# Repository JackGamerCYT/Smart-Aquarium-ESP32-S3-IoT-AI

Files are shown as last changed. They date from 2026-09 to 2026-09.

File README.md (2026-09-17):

# 🐠 SMART AQUARIUM IoT – BỂ CÁ THÔNG MINH (ESP32-S3)

Hệ thống quản lý bể cá mini 4.5 L: **tự động làm mát** bằng sò Peltier (hysteresis 25.5–27.0°C), **cho cá ăn theo lịch thời gian thực** (RTC DS3231 – chạy cả khi mất Internet/mất điện), hiển thị OLED tại chỗ và **giám sát/điều khiển từ xa** qua MQTT + Web Dashboard trên Vercel.

> Môn **Embedded System Design** – GVHD: Huỳnh Hoàng Hà – Trường ĐH Sư phạm Kỹ thuật TP.HCM (HCMUTE)
> Trạng thái: **Tuần 6 – System Integration** · Firmware **v2.2.0** · Dashboard **v4** · **Vercel API + Postgres (Neon) + HiveMQ** · Phần cứng **Rev2**

## 📁 Cấu trúc repository

```text
smart-aquarium-ai/
├── README.md                         # README tổng (file này)
├── index.html                        # Web Dashboard v4 (HiveMQ realtime + Vercel API + Chart.js)
├── api/                              # Vercel Functions: ingest, history, stats, feeds, events, export, config, health, cron
├── lib/                              # Kết nối Postgres (pg), tiện ích HTTP, schema
├── db/schema.sql                     # Cấu trúc bảng (API tự tạo, không cần chạy tay)
├── package.json                      # Dependency: pg
├── vercel.json                       # Cron dọn dữ liệu + header
├── .env.example                      # Danh sách Environment Variables
├── docs/
│   ├── README.md
│   ├── 01_TONG_KET_KET_QUA_TUAN.md    # Tổng kết kết quả từng tuần (W1 → W6)
│   ├── 02_DAC_TA_HE_THONG.md          # Đặc tả: yêu cầu, FR/NFR, kiến trúc, MQTT, state machine
│   ├── 03_LO_TRINH_TIEN_DO_PHAN_CONG.md # Lộ trình 9 tuần, tiến độ, phân công, quản lý cá nhân
│   ├── 04_PHAN_CUNG_REV2_RTC.md       # Làm lại toàn bộ mạch + tích hợp RTC DS3231
│   └── 05_WEB_DATABASE.md             # Triển khai Vercel + Postgres + HiveMQ (public/Cloud)
├── firmware/
│   ├── README.md
│   └── smart_aquarium_esp32s3/
│       └── smart_aquarium_esp32s3.ino # Firmware v2.2.0
├── hardware/
│   ├── README.md
│   └── danh_sach_mua_sam_v1.1.xlsx     # BOM & dự toán (cập nhật Rev2)
├── report/
│   ├── README.md
│   └── Report_Chuong1_2.docx           # Báo cáo: Chương 1 Tổng quan, Chương 2 Cơ sở lý thuyết
└── weekly/
    └── W06/README.md                  # Bản nộp tuần 6
```

## ⚙️ Tính năng chính (v2.2.0)

| Nhóm | Tính năng |
|---|---|
| Nhiệt độ | DS18B20 đọc bất đồng bộ 1 s · hysteresis AUTO · MANUAL tự hết hạn 30 phút · nghỉ tối thiểu 60 s · quạt chạy trễ 60 s |
| Cho ăn | Servo MG90S · nút FEED / Web / **lịch tối đa 4 mốc theo RTC** · tạm dừng bơm · chống cho ăn lặp & quá tay |
| Thời gian | **DS3231** giữ giờ bằng pin · NTP → RTC · đặt giờ từ trình duyệt · ngắt SQW 1 Hz |
| An toàn | Lỗi cảm biến → tắt sò · ≥30°C ép bật · ≤22°C ép tắt · bơm tắt → khóa sò · còi cảnh báo |
| IoT | MQTT HiveMQ public (1883) hoặc **HiveMQ Cloud (TLS 8883 + user/pass)** · telemetry 2 s · event · LWT online/offline · **ACK cho mỗi lệnh web** · lưu cấu hình NVS |
| Database | **Vercel Functions + Postgres (Neon)**: ESP32 gửi theo lô lên `/api/ingest` (task FreeRTOS riêng) · web vẽ lịch sử 1h–7 ngày, KPI, cho ăn theo ngày, nhật ký, xuất CSV · cron dọn dữ liệu cũ |

## 📌 Sơ đồ chân Rev2 (tóm tắt)

| Linh kiện | GPIO | Ghi chú |
|---|---|---|
| DS18B20 | 4 | Trở kéo 4.7k lên **3V3** |
| OLED SH1106 + DS3231 (I2C) | SDA 8 / SCL 9 | Cấp **3V3**, 0x3C / 0x68 |
| DS3231 SQW | 7 | Ngắt 1 Hz |
| Relay CH1 – Sò Peltier | 19 | Active-LOW (giữ như mạch cũ) |
| Relay CH2 – Bơm | 18 | Active-LOW (giữ như mạch cũ) |
| Quạt (IRLZ44N) | 15 | Chạy trễ 60 s |
| Servo MG90S | 13 | Tụ 1000 µF |
| Còi | 12 | như mạch cũ |
| Nút BOOT / FEED | 0 / 16 | Giữ BOOT 2 s = Self-Test |

Chi tiết đấu nối, nguồn 12V-10A, quy trình bring-up: **[docs/04_PHAN_CUNG_REV2_RTC.md](docs/04_PHAN_CUNG_REV2_RTC.md)**

## 🚀 Bắt đầu nhanh

1. **Firmware:** xem [firmware/README.md](firmware/README.md) – cài thư viện, sửa Wi-Fi & `TOPIC_BASE`, nạp bằng Arduino IDE.
2. **Vercel + Database + HiveMQ:** push GitHub → Vercel **Storage → Neon** → nhập Environment Variables (xem `.env.example`) → Redeploy. Chi tiết: [docs/05_WEB_DATABASE.md](docs/05_WEB_DATABASE.md).
3. **Kiểm tra:** mở `https://<app>.vercel.app/api/health`.
4. **Phần cứng:** lắp theo thứ tự B1 → B10 trong `docs/04`.

## 👥 Nhóm

Xem bảng thành viên & phân công: [docs/03_LO_TRINH_TIEN_DO_PHAN_CONG.md](docs/03_LO_TRINH_TIEN_DO_PHAN_CONG.md)

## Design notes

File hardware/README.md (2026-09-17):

# Hardware

- `danh_sach_mua_sam_v1.1.xlsx` – BOM & dự toán. Cột **"Thay đổi v1.1"** ghi rõ mục thay/bổ sung so với v1.0 (OLED thay TFT, nguồn 10A, relay, bơm, cầu chì, driver, connector). Giá mục mới là ước tính.
- Sơ đồ đấu nối, ngân sách công suất, bố trí PCB, quy trình bring-up: `../docs/04_PHAN_CUNG_REV2_RTC.md`
- Ảnh mạch thực tế / sơ đồ vẽ tay: đặt vào thư mục `hardware/images/` khi hàn xong.

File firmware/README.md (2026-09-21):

# Firmware – ESP32-S3 (v3.2.0)

## Cài đặt
1. Arduino IDE → *Preferences* → Board URL: `https://espressif.github.io/arduino-esp32/package_esp32_index.json`
2. *Boards Manager* → cài **esp32 by Espressif** (2.0.x hoặc 3.x) → chọn **ESP32S3 Dev Module**
   (PSRAM: *OPI PSRAM* cho N8R8/N16R8 · Flash size theo board)
3. *Library Manager* cài: `PubSubClient`, `ArduinoJson` (v7), `OneWire`, `DallasTemperature`, `ESP32Servo`, `RTClib` (Adafruit).
   **Màn LCD không cần thư viện** – driver đã viết sẵn trong firmware. (Không cần U8g2 / LiquidCrystal_I2C / Adafruit GFX.)
4. Wi-Fi `HO TRO SINH VIEN`, topic `smartaquarium_node2026` đã điền sẵn. Giữ `DB_ENABLED = false` (backend Render ghi database).
5. Cắm USB vào cổng **UART/COM** → Upload → Serial Monitor **115200**.

## Thư mục
| Sketch | Dùng khi |
|---|---|
| `smart_aquarium_esp32s3/` | Firmware chính |
| `test_lcd/` | Kiểm tra riêng màn LCD (tô kín ô, hiện chữ 4 dòng) |
| `test_tim_chan_i2c/` | Tự dò LCD/RTC đang thật sự cắm ở chân nào, đo điện dây SDA/SCL |
| `test_ds18b20/` | Web báo **Mất cảm biến / ERR**: kiểm tra trở kéo, dò chân, đọc 20 lần đếm lỗi |

## Sơ đồ chân (giữ nguyên mạch cũ)
| Chức năng | GPIO | Ghi chú |
|---|---|---|
| LCD + DS3231 – SDA / SCL | **8 / 9** | LCD cấp **5V** (qua module chuyển mức BSS138 nếu có), DS3231 cấp 3V3 |
| DS18B20 | 4 | ĐỎ→3V3 · ĐEN→GND · VÀNG→GPIO4 · **trở 4.7k giữa VÀNG và ĐỎ** (kéo nội chỉ dùng tạm) |
| DS3231 SQW | 7 | Tùy chọn |
| Relay sò / bơm | 19 / 18 | Active-LOW |
| Quạt MOSFET / Servo / Còi | 15 / 13 / 12 | |
| Nút BOOT / Cho ăn | 0 / 16 | Giữ BOOT 2 s = Self-Test |

## Màn LCD I2C
- **LCD 1602 (16x2):** tự lật trang mỗi 3 s — giờ & nhiệt độ → sò/bơm & lịch cho ăn → (cảnh báo nếu có).
- **LCD 2004 (20x4):** hiện đủ trên 1 trang.
- Đổi loại màn **không cần nạp lại**: gõ `lcd 1602` hoặc `lcd 2004` ở Serial, hoặc bấm nút trên web (lưu NVS).

| Hiện tượng | Nguyên nhân | Cách sửa |
|---|---|---|
| Đèn nền sáng, không có chữ / chỉ thấy ô đen | Tương phản | **Vặn biến trở xanh** sau lưng mạch I2C |
| Đèn nền không sáng | Thiếu 5V/GND, hoặc mất jumper LED | Kiểm tra VCC=5V, cắm jumper "LED" sau mạch I2C |
| Serial `[I2C] ... KHONG CO` | Dây / nguồn | SDA→GPIO8, SCL→GPIO9 (hay bị đảo), GND chung |
| Serial `[LCD] KHONG thay LCD` nhưng có `68` | Dây riêng của LCD | Nạp `test_tim_chan_i2c.ino` |
| Chữ bị cắt / sai dòng | Chọn sai kích thước | `lcd 1602` / `lcd 2004` |

## Lệnh Serial Monitor (Newline)
`so on` · `so off` · `bom on` · `bom off` · `an` · `auto` · `test` · `status` · `lcd test` · `lcd 1602` · `lcd 2004` · `i2c`

## Cấu trúc code
| Mục | Hàm chính |
|---|---|
| Thời gian thực | `initTime()`, `handleTimeSync()`, `seedSystemFromRtc()`, `writeRtcFromSystem()` |
| Nhiệt độ | `updateSensor()`, `controlTemperature()`, `setChiller()` |
| Cho ăn | `startFeeding()`, `updateFeeding()` (FSM), `checkSchedule()` |
| LCD (driver tự viết) | `lcdInit()`, `lcdRow()` (chỉ ghi dòng thay đổi), `renderLCD()`, `lcdTestPattern()`, `handleLcdHotplug()` |
| Chẩn đoán I2C | `i2cLineHasPullup()`, `i2cScan()`, `printI2cReport()` |
| IoT | `handleConnectivity()`, `sendTelemetry()`, `mqttCallback()` + `sendAck()`, `publishEvent()` |
| Độ tin cậy | `bufferPush()` / `bufferFlush()` (đệm 240 bản ghi + gửi bù), SAFE MODE sau 30 s mất broker |
| Bảo trì | `runSelfTest()`, `handleSerialCommand()` |

## Kiểm tra đã thực hiện
- Kiểm tra cú pháp C++ (g++ -Wall -Wextra, header giả lập Arduino + ArduinoJson thật): **0 lỗi**.
- Driver LCD chạy trên bộ **mô phỏng HD44780 + PCF8574**: khởi tạo 4-bit đúng, hiển thị đúng cả 16x2 và 20x4.
- ⚠️ **Chưa biên dịch bằng toolchain ESP32 và chưa chạy trên phần cứng thật** → bấm Verify trong Arduino IDE trước khi nạp.

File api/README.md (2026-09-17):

# API (Vercel Functions)

| Endpoint | Method | Dùng bởi | Mô tả |
|---|---|---|---|
| `/api/ingest` | POST | ESP32 | Header `x-device-key`. Body `{"items":[{"t":"telemetry"\|"events","r":{...}}]}` (≤ 60) |
| `/api/history?hours=24` | GET | Web | Nhiệt độ avg/min/max + % sò chạy theo bucket |
| `/api/stats?hours=24` | GET | Web | KPI |
| `/api/feeds?days=7` | GET | Web | Số lần cho ăn/ngày |
| `/api/events?type=&limit=100` | GET | Web | Nhật ký |
| `/api/export?hours=24` | GET | Web | CSV |
| `/api/config` | GET | Web | MQTT URL, topic, tài khoản web (từ env) |
| `/api/health` | GET | Người dùng | Kiểm tra env + DB |
| `/api/cron/cleanup` | GET | Vercel Cron | Xóa dữ liệu cũ (`Authorization: Bearer CRON_SECRET`) |

Biến môi trường: xem `../.env.example`. Hướng dẫn: `../docs/05_WEB_DATABASE.md`.

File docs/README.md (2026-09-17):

# Docs

| File | Nội dung |
|---|---|
| `01_TONG_KET_KET_QUA_TUAN.md` | Kết quả W1–W6, minh chứng, vướng mắc |
| `02_DAC_TA_HE_THONG.md` | Requirement analysis, FR/NFR, kiến trúc, interface, MQTT, state machine, traceability |
| `03_LO_TRINH_TIEN_DO_PHAN_CONG.md` | Roadmap 9 tuần, bảng task W6, kế hoạch W7–W9, rủi ro, quản lý công việc cá nhân |
| `04_PHAN_CUNG_REV2_RTC.md` | Lỗi mạch Rev1 & cách làm lại, pinout Rev2, đấu nối RTC DS3231, bring-up, test case RTC |
| `05_WEB_DATABASE.md` | Kiến trúc Web ↔ Vercel API/Postgres ↔ ESP32 ↔ HiveMQ, luồng ACK, API, triển khai từng bước, lỗi thường gặp |

Sơ đồ `mermaid` hiển thị trực tiếp trên GitHub.

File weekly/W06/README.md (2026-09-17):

# Tuần 6 – System Integration (14/09 – 20/09/2026)

**Output yêu cầu:** Integrated System / Prototype

## Nộp tuần này
| Hạng mục | File |
|---|---|
| Tổng kết kết quả từng tuần | `docs/01_TONG_KET_KET_QUA_TUAN.md` |
| Đặc tả hệ thống | `docs/02_DAC_TA_HE_THONG.md` |
| Lộ trình / tiến độ / phân công | `docs/03_LO_TRINH_TIEN_DO_PHAN_CONG.md` |
| Làm lại mạch + RTC (Rel) | `docs/04_PHAN_CUNG_REV2_RTC.md` |
| Firmware v2.0.0 | `firmware/smart_aquarium_esp32s3/` |
| Web v2 | `index.html` |
| BOM v1.1 | `hardware/danh_sach_mua_sam_v1.1.xlsx` |
| Report Chương 1, 2 | `report/Report_Chuong1_2.docx` |

## Minh chứng (bổ sung khi có)
- [ ] Ảnh mạch Rev2 đã hàn
- [ ] Ảnh I2C scanner thấy 0x3C / 0x57 / 0x68
- [ ] Video 3 use case tích hợp
- [ ] Link Vercel: …

## Lệnh push
```bash
git add .
git commit -m "W6: System integration - HW Rev2 + RTC DS3231, FW v2.0.0, docs, report ch1-2"
git push
```

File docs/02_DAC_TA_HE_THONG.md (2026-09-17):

# 02 – ĐẶC TẢ HỆ THỐNG: BỂ CÁ THÔNG MINH IoT (SMART AQUARIUM)

| Mục | Nội dung |
|---|---|
| Môn học | Embedded System Design – GVHD: Huỳnh Hoàng Hà – HCMUTE |
| Phiên bản tài liệu | v2.0 (cập nhật Tuần 6 – System Integration) |
| Phần cứng | ESP32-S3 DevKitC-1 · DS18B20 · DS3231 RTC · OLED 1.3" SH1106 · Relay 2 kênh · TEC1-12706 · MG90S |
| Phần mềm | Firmware Arduino C++ (FW 2.0.0) · Web Dashboard (HTML/Tailwind/MQTT.js/Chart.js) trên Vercel |
| Truyền thông | MQTT qua HiveMQ public broker (TCP 1883 cho thiết bị, WSS 8884 cho web) |

---

## 1. Bài toán & mục tiêu

Bể cá mini ~4.5 L (20×14×16 cm) có thể tích nước nhỏ nên **nhiệt độ thay đổi rất nhanh** theo nhiệt độ phòng (mùa nóng tại TP.HCM phòng có thể 32–35°C), trong khi đa số cá cảnh nhiệt đới sống tốt ở **24–28°C**. Người nuôi còn thường xuyên **quên cho cá ăn** hoặc cho ăn quá nhiều khi vắng nhà.

Hệ thống cần:
1. Giữ nhiệt độ nước trong dải an toàn một cách tự động.
2. Cho cá ăn tự động theo **giờ cố định**, kể cả khi mất Internet hoặc sau khi mất điện.
3. Cho phép theo dõi và điều khiển tại chỗ (màn hình, nút) và từ xa (web).
4. Cảnh báo khi có sự cố (quá nóng, quá lạnh, hỏng cảm biến, mất giờ).

## 2. Phạm vi

| Trong phạm vi | Ngoài phạm vi (hướng phát triển) |
|---|---|
| Làm **mát** bằng sò Peltier + water block | Sưởi nước (cần thêm heater) |
| Đo nhiệt độ nước 1 điểm | Đo pH, TDS, oxy hòa tan, mực nước |
| Cho ăn thức ăn dạng hạt khô bằng hộc xoay | Định lượng thức ăn theo gram |
| Điều khiển qua MQTT broker công cộng | Xác thực người dùng, TLS phía thiết bị, broker riêng |
| Lưu cấu hình/bộ đếm trên NVS của ESP32 | Cơ sở dữ liệu lịch sử dài hạn + phân tích AI (tùy chọn giai đoạn sau) |

---

## 3. Phân tích yêu cầu (Requirement Analysis – W1)

| Vấn đề / Use case | Nhu cầu người dùng | Câu hỏi phân tích | Giải pháp đề xuất |
|---|---|---|---|
| Nước nóng lên theo phòng | Nhiệt độ luôn an toàn cho cá | Làm mát bằng gì? Khi nào bật/tắt? | Cảm biến nhiệt chống nước + sò Peltier + điều khiển trễ (hysteresis) |
| Quên cho cá ăn | Cá được ăn đúng giờ | Mất mạng / mất điện thì sao? | Servo hộc xoay + **RTC có pin** + lịch lưu trong bộ nhớ |
| Cho ăn quá nhiều | Tránh bẩn nước, cá bệnh | Giới hạn thế nào? | Khoảng cách tối thiểu giữa 2 lần + giới hạn số lần/ngày |
| Thức ăn bị bơm hút | Thức ăn không bị lọc mất | Khi nào tắt bơm? | Tạm dừng bơm trong lúc cho ăn |
| Muốn xem tình trạng tại bể | Biết nhanh nhiệt độ, trạng thái | Hiển thị gì? | Màn hình OLED |
| Vắng nhà | Xem & điều khiển từ xa | Qua kênh nào? | Wi-Fi + MQTT + Web dashboard |
| Thiết bị hỏng âm thầm | Được báo sự cố | Phát hiện thế nào? | Kiểm tra giá trị cảm biến, còi, cảnh báo web |
| Bảo trì, lắp ráp | Kiểm tra nhanh phần cứng | Làm sao test không cần code? | Chế độ Self-Test bằng nút / web |

---

## 4. Yêu cầu chức năng (Functional Requirements – W2)

| ID | Yêu cầu | Đặc tả (hệ thống PHẢI…) | Kiểm chứng | TC |
|---|---|---|---|---|
| FR01 | Đo nhiệt độ | Đo nhiệt độ nước chu kỳ **1 s**, độ phân giải 0.125°C, sai số ≤ ±0.5°C | So sánh nhiệt kế chuẩn tại 3 điểm (≈20, 26, 32°C) | TC01 |
| FR02 | Làm mát tự động | Ở chế độ AUTO: bật sò khi T ≥ **SP_ON (27.0°C)**, tắt khi T ≤ **SP_OFF (25.5°C)** | Ngâm cảm biến nước ấm/mát, quan sát relay | TC02 |
| FR03 | Bảo vệ relay | Không bật lại sò trong **60 s** kể từ lần tắt gần nhất | Dao động T quanh ngưỡng, đo khoảng thời gian | TC03 |
| FR04 | Quạt tản nhiệt | Quạt chạy khi sò chạy và **thêm 60 s** sau khi sò tắt | Quan sát quạt sau khi tắt sò | TC04 |
| FR05 | Chế độ vận hành | Hỗ trợ **AUTO / MANUAL**; MANUAL tự trở về AUTO sau **30 phút** | Bật tay từ web, chờ hết hạn | TC05 |
| FR06 | Cho ăn thủ công | Cho ăn khi nhấn nút FEED hoặc lệnh web; servo 0°→110°→0° | Nhấn nút, quan sát hộc | TC06 |
| FR07 | Cho ăn theo lịch | Cho ăn tại tối đa **4 mốc giờ/ngày** theo giờ RTC, **không cần Internet** | Đặt lịch, ngắt Wi-Fi | TC07 |
| FR08 | Giữ thời gian | Giữ giờ khi mất điện nhờ DS3231 + pin; đồng bộ NTP khi có mạng; cho phép đặt giờ từ web | Rút điện 10 phút, bật lại không mạng | TC08 |
| FR09 | Chống cho ăn sai | Không cho ăn lặp sau reset; bỏ mốc nếu vừa cho ăn < 30 phút; tối đa **6 lần/ngày**; cho ăn bù nếu trễ ≤ 30 phút | Reset / bấm liên tục | TC09 |
| FR10 | Tạm dừng bơm | Tắt bơm khi bắt đầu cho ăn, bật lại **5 s** sau khi hộc đóng | Quan sát relay bơm | TC10 |
| FR11 | Hiển thị tại chỗ | OLED hiển thị: giờ, Wi-Fi/MQTT/RTC, nhiệt độ, chế độ, sò, bơm, quạt, lần ăn kế tiếp, số lần ăn, cảnh báo; làm mới 0.5 s | Quan sát | TC11 |
| FR12 | Giám sát từ xa | Gửi telemetry JSON mỗi **2 s**; dashboard hiển thị & vẽ biểu đồ | Mở web, so với OLED | TC12 |
| FR13 | Điều khiển từ xa | Nhận lệnh: sò, bơm, chế độ, cho ăn, self-test, lịch, ngưỡng, giờ, tắt còi | Gửi từng lệnh | TC13 |
| FR14 | Cảnh báo & an toàn | Lỗi cảm biến → tắt sò + còi; T ≥ 30°C → ép bật sò + còi; T ≤ 22°C → ép tắt sò + còi; bơm tắt → khóa sò | Rút DS18B20, ngâm nước nóng/lạnh | TC14 |
| FR15 | Self-Test | Kiểm tra còi, 2 relay, quạt, servo, DS18B20, RTC; báo PASS/FAIL trên OLED + web | Giữ BOOT 2 s | TC15 |
| FR16 | Lưu cấu hình | Lịch, ngưỡng, bộ đếm lưu NVS, không mất khi mất điện | Đổi lịch, rút điện | TC16 |

## 5. Yêu cầu phi chức năng (NFR)

| ID | Loại | Đặc tả |
|---|---|---|
| NFR01 | Thời gian đáp ứng | Lệnh web → cơ cấu chấp hành ≤ **1 s** (mạng ổn định) |
| NFR02 | Non-blocking | Vòng `loop()` không chặn quá 50 ms khi vận hành bình thường (trừ Self-Test) |
| NFR03 | Độ chính xác giờ | Lệch ≤ ±2 ppm (≈ ±1 phút/năm) khi offline nhờ DS3231 TCXO |
| NFR04 | Tin cậy | Tự kết nối lại Wi-Fi (30 s) & MQTT (5 s); không reset khi servo chạy |
| NFR05 | An toàn điện | Mọi chân tín hiệu ESP32 ≤ 3.3 V; có cầu chì; tải 12V dùng tiếp điểm NO |
| NFR06 | Nguồn | Toàn hệ chạy từ 1 adapter 12V-10A |
| NFR07 | Bảo trì | Module cắm bằng connector, có Self-Test, tài liệu README cho từng thư mục |
| NFR08 | Bảo mật (mức môn học) | Topic MQTT riêng theo nhóm; LWT báo online/offline |

---

## 6. Kiến trúc hệ thống (W3)

### 6.1 Sơ đồ khối tổng thể

```mermaid
flowchart TB
  subgraph INPUT
    DS18["DS18B20 (1-Wire)"]
    RTC["DS3231 RTC (I2C + SQW)"]
    BTN["Nút FEED / BOOT"]
  end
  subgraph MCU["ESP32-S3"]
    APP["Application: điều khiển nhiệt, lịch cho ăn, an toàn"]
  end
  subgraph OUTPUT
    R1["Relay CH1 → Sò Peltier"]
    R2["Relay CH2 → Bơm lọc"]
    FAN["MOSFET → Quạt"]
    SERVO["Servo MG90S → Hộc thức ăn"]
    OLED["OLED 1.3 SH1106"]
    BUZ["Còi"]
  end
  subgraph CLOUD
    BROKER["HiveMQ MQTT Broker"]
    WEB["Web Dashboard (Vercel)"]
    NTP["NTP server"]
  end
  DS18 --> APP
  RTC --> APP
  BTN --> APP
  APP --> R1 & R2 & FAN & SERVO & OLED & BUZ
  APP <-->|"Wi-Fi MQTT"| BROKER
  BROKER <-->|"WebSocket"| WEB
  NTP -->|"SNTP"| APP
```

### 6.2 Kiến trúc phần mềm firmware (phân lớp)

```text
┌───────────────────────────────────────────────────────────────┐
│ APPLICATION : controlTemperature() · checkSchedule() ·        │
│               handleAlarm() · mqttCallback() · runSelfTest()  │
├───────────────────────────────────────────────────────────────┤
│ SERVICES    : Time service (RTC⇄System⇄NTP) · Feed FSM ·      │
│               Buzzer FSM · Telemetry/Event · NVS settings     │
├───────────────────────────────────────────────────────────────┤
│ DRIVERS/LIB : DallasTemperature · RTClib · Adafruit_SH110X ·  │
│               ESP32Servo · PubSubClient · ArduinoJson         │
├───────────────────────────────────────────────────────────────┤
│ HAL (Arduino-ESP32 / ESP-IDF): GPIO · I2C · LEDC PWM · Wi-Fi ·│
│               SNTP · NVS · Interrupt                          │
├───────────────────────────────────────────────────────────────┤
│ HARDWARE    : ESP32-S3 + ngoại vi                             │
└───────────────────────────────────────────────────────────────┘
```

### 6.3 Phân chia HW/SW

| Chức năng | Phần cứng | Phần mềm |
|---|---|---|
| Đo nhiệt | DS18B20 + trở kéo | Đọc bất đồng bộ, lọc giá trị lỗi (−127, 85, ngoài 0–50°C) |
| Làm mát | Relay CH1, sò, water block, quạt, MOSFET | Hysteresis, thời gian nghỉ tối thiểu, quạt chạy trễ |
| Cho ăn | Servo MG90S, hộc xoay, tụ đệm | FSM quét góc, lịch RTC, chống cho ăn lặp |
| Thời gian | DS3231 (TCXO) + CR2032 | Đồng bộ NTP ⇄ RTC, múi giờ UTC+7, nhịp 1 Hz qua ngắt |
| HMI | OLED, còi, 2 nút | Giao diện OLED, mẫu tiếng còi, debounce nút |
| Kết nối | Wi-Fi ESP32-S3 | MQTT, JSON, tự kết nối lại, LWT |

### 6.4 Danh sách giao tiếp (Interface list)

| Giao tiếp | Thiết bị | Thông số |
|---|---|---|
| 1-Wire | DS18B20 | GPIO4, 11-bit (375 ms/lần chuyển đổi) |
| I2C | OLED SH1106 (0x3C), DS3231 (0x68), AT24C32 (0x57) | GPIO8 SDA / GPIO9 SCL, 400 kHz, 3V3 |
| GPIO ngắt | DS3231 SQW | GPIO7, FALLING, 1 Hz |
| GPIO ra | Relay CH1/CH2 (Active-LOW), MOSFET quạt, còi | GPIO19, GPIO18, GPIO15 (tùy chọn), GPIO12 |
| PWM | Servo | GPIO13, 50 Hz, 500–2400 µs |
| GPIO vào | Nút BOOT / FEED | GPIO0 / GPIO16, INPUT_PULLUP |
| Wi-Fi/MQTT | HiveMQ | `broker.hivemq.com:1883` (thiết bị), `wss://…:8884/mqtt` (web) |

### 6.5 Giao thức MQTT

`TOPIC_BASE = smartaquarium_node2026`

| Topic | Hướng | QoS/Retain | Nội dung |
|---|---|---|---|
| `…/telemetry` | ESP32 → Web | 0 / không | JSON trạng thái mỗi 2 s |
| `…/command` | Web → ESP32 | 0 / không | JSON lệnh |
| `…/status` | ESP32 → Web | 1 / **retain** | `online` / `offline` (LWT) |
| `…/event` | ESP32 → Web | 0 / không | Sự kiện: feed, alarm, time_sync, self_test… |

**Telemetry mẫu**
```json
{"temp":26.1,"chiller":false,"pump":true,"fan":false,"mode":"AUTO",
 "feed_today":1,"feed_count":12,"feeding":false,"time":"2026-09-17 10:21:05",
 "time_src":"NTP","rtc_ok":true,"rtc_temp":28.5,"next_feed":"17:30",
 "schedule":"07:00,17:30","sp_on":27,"sp_off":25.5,"alarm":"NONE",
 "rssi":-61,"uptime":3605,"fw":"2.0.0"}
```

**Lệnh**

| `device` | Tham số | Tác dụng |
|---|---|---|
| `chiller` | `action: ON/OFF` | Bật/tắt sò, chuyển MANUAL 30 phút |
| `pump` | `action: ON/OFF` | Bật/tắt bơm (tắt bơm ⇒ khóa sò) |
| `mode` | `action: AUTO/MANUAL` | Đổi chế độ |
| `feed` | – | Cho ăn ngay |
| `test` | – | Self-Test |
| `schedule` | `slots: "07:00,17:30"` | Đặt lịch (chuỗi rỗng = tắt) |
| `setpoint` | `on: 27.0, off: 25.5` | Đổi ngưỡng (off ≤ on − 0.5) |
| `time` | `epoch: 1789627265` | Đặt giờ từ trình duyệt → RTC |
| `alarm` | `action: MUTE` | Tắt còi cảnh báo hiện tại |

---

## 7. Hành vi hệ thống (State machine)

### 7.1 Điều khiển nhiệt độ

```mermaid
stateDiagram-v2
  [*] --> OFF
  OFF --> ON: T ≥ SP_ON và đã nghỉ ≥ 60s và bơm bật
  ON --> OFF: T ≤ SP_OFF
  ON --> OFF: lỗi cảm biến / T ≤ 22°C / bơm tắt
  OFF --> ON: T ≥ 30°C (ép bật, báo động)
```

### 7.2 Cho ăn

```mermaid
stateDiagram-v2
  [*] --> IDLE
  IDLE --> OPEN: nút / web / đến mốc lịch (tắt bơm)
  OPEN --> HOLD: servo đạt 110°
  HOLD --> CLOSE: sau 1 s
  CLOSE --> RESUME: servo về 0°, detach
  RESUME --> IDLE: sau 5 s bật lại bơm, +1 bộ đếm, lưu NVS
```

### 7.3 Nguồn thời gian

```text
Khởi động ─► DS3231 còn giờ? ─ có ─► giờ hệ thống = RTC (src=RTC)
                    │ không
                    ▼
            chờ NTP / lệnh web ─► (TIME_INVALID: tạm dừng lịch)
NTP đồng bộ ─► giờ hệ thống = NTP ─► ghi vào RTC (lần đầu + mỗi 6 giờ)
Mất Wi-Fi   ─► mỗi 10 phút nạp lại giờ hệ thống từ RTC (TCXO chính xác hơn thạch anh ESP32)
```

---

## 8. Ma trận truy vết (Traceability)

| Requirement | Chức năng firmware | Test case |
|---|---|---|
| FR01 | `updateSensor()` | TC01 |
| FR02, FR03, FR04 | `controlTemperature()`, `setChiller()`, `applyOutputs()` | TC02–TC04 |
| FR05 | `controlTemperature()` (MANUAL_TIMEOUT_MS) | TC05 |
| FR06, FR10 | `startFeeding()`, `updateFeeding()` | TC06, TC10 |
| FR07, FR09 | `checkSchedule()` | TC07, TC09, TC-RTC-04..07 |
| FR08 | `initTime()`, `handleTimeSync()`, lệnh `time` | TC08, TC-RTC-01..03, 08..10 |
| FR11 | `renderOLED()` | TC11 |
| FR12, FR13 | `sendTelemetry()`, `mqttCallback()` | TC12, TC13 |
| FR14 | `controlTemperature()`, `handleAlarm()` | TC14 |
| FR15 | `runSelfTest()` | TC15 |
| FR16 | `loadSettings()`, `saveFeedCounters()` | TC16 |

## 9. Ràng buộc & giả định

- Bể 4.5 L, phòng ≤ 35°C; sò 60 W đủ hạ vài °C cho thể tích này khi mặt nóng được tản nhiệt tốt (cần đo thực tế ở W7).
- Thức ăn dạng hạt khô, không vón cục.
- Wi-Fi 2.4 GHz; broker HiveMQ công cộng chỉ phục vụ học tập.
- Chi tiết mạch điện, bảng nối chân và quy trình lắp: xem **`docs/04_PHAN_CUNG_REV2_RTC.md`**.

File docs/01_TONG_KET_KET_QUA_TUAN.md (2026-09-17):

# 01 – TỔNG KẾT KẾT QUẢ THEO TUẦN

> Dự án: **Bể cá thông minh IoT (Smart Aquarium)** – Môn Embedded System Design (HCMUTE)
> Cập nhật: **17/09/2026 – Tuần 6** · Quy ước: ✅ hoàn thành · 🔄 đang làm · ⏳ chưa làm · ⚠️ phải làm lại
> *Ngày của từng tuần là dự kiến theo lịch 9 tuần – nhóm chỉnh lại theo lịch lớp thực tế. Cột "Minh chứng" điền link commit/ảnh/video.*

## Tổng quan tiến độ

| Tuần | Giai đoạn (theo roadmap môn) | Output yêu cầu | Trạng thái |
|---|---|---|---|
| W1 | Introduction & Requirement Analysis | Requirement Analysis + Proposed Solutions | ✅ |
| W2 | System Specification | System Specification | ✅ (bổ sung v2.0 ở W6) |
| W3 | Architecture & HW/SW Design | Architecture + HW/SW Design + BOM | ✅ (⚠️ sửa pinout/nguồn ở W6) |
| W4 | Prototype & Feasibility Validation | Validated Modules + Test Results | ✅ phần lớn module |
| W5 | Implementation | Working Modules + Source Code | ✅ FW v1 + Web v1 |
| W6 | System Integration | Integrated System / Prototype | 🔄 Rev2 phần cứng + RTC + FW v2 |
| W7 | Testing & Optimization | Test Results + Improved System | ⏳ |
| W8 | Finalization & Presentation | Final Prototype + Report + Slide | ⏳ (Report Ch.1–2 đã xong ở W6) |
| W9 | Evaluation | Final Evaluation | ⏳ |

---

## Tuần 1 – Phân tích yêu cầu
**Câu hỏi trung tâm:** *Hệ thống giải quyết vấn đề gì?*

| Kết quả | Minh chứng |
|---|---|
| Xác định bài toán: bể mini 4.5 L nóng nhanh theo phòng; quên/cho ăn quá tay khi vắng nhà | `docs/02_DAC_TA_HE_THONG.md` §1 |
| Bảng Requirement Analysis (8 use case) + giải pháp đề xuất | `docs/02_DAC_TA_HE_THONG.md` §3 |
| Thành lập nhóm, tạo repo GitHub, nhóm Zalo | Link repo: `…` |

## Tuần 2 – Đặc tả hệ thống
**Câu hỏi trung tâm:** *Hệ thống chính xác phải làm gì?*

| Kết quả | Minh chứng |
|---|---|
| Đặc tả chức năng: làm mát hysteresis 25.5–27.0°C, cho ăn servo, OLED, IoT MQTT | `TONG_HOP_HE_THONG_HO_CA_SMART.md` |
| Chọn phương án làm mát bằng sò Peltier + water block (thay vì quạt thổi mặt nước) | Slide/biên bản nhóm |
| **Bổ sung W6:** 16 FR + 8 NFR có tiêu chí kiểm chứng, ma trận truy vết | `docs/02_DAC_TA_HE_THONG.md` §4, §5, §8 |

## Tuần 3 – Kiến trúc & thiết kế HW/SW
**Câu hỏi trung tâm:** *Tổ chức hệ thống như thế nào?*

| Kết quả | Minh chứng |
|---|---|
| Chọn ESP32-S3 DevKitC (Wi-Fi, PSRAM, dư GPIO), DS18B20 chống nước, MG90S, TEC1-12706 | `README.md` |
| Bảng dự toán & mua sắm linh kiện v1.0 (23/08/2026) | `danh_sach_mua_sam_ho_ca_smart.xlsx` |
| Sơ đồ nối chân Rev1, phân phối nguồn 12V/5V | `TONG_HOP_HE_THONG_HO_CA_SMART.md` §3–4 |
| ⚠️ **Phát hiện ở W6:** BOM ghi TFT ST7789 nhưng thiết kế dùng OLED I2C; thiếu relay & bơm; nguồn 5A không đủ; GPIO19 trùng USB | `docs/04_PHAN_CUNG_REV2_RTC.md` §1 |

## Tuần 4 – Thử nghiệm module
**Câu hỏi trung tâm:** *Linh kiện đã chọn có chạy được không?*

> ⚠️ Bảng này được tổng hợp từ các lỗi đã ghi trong README/TONG_HOP v1 – **nhóm kiểm tra lại và sửa PASS/FAIL cho đúng thực tế** trước khi nộp.

| Module | Test cơ bản | Kết quả | Ghi chú / hành động |
|---|---|---|---|
| ESP32-S3 | Blink, Wi-Fi scan | PASS | – |
| DS18B20 | Đọc nhiệt độ | PASS | ⚠️ trở kéo đang lên 5V → sửa lên 3V3 |
| OLED 1.3" | Hiển thị chữ | PASS* | *Dùng lib SSD1306 cho chip SH1106 → lệch cột → đổi lib |
| Relay 2 kênh | ON/OFF | FAIL một phần | IN1 sáng đỏ liên tục → nguyên nhân: mức 3.3V không tắt opto khi VCC=5V |
| Servo MG90S | Sweep 0–110° | PASS* | *Reset `BROWNOUT_RST` khi chạy bằng USB → dùng nguồn ngoài + sweep chậm |
| Còi active | Bíp | PASS | Âm nhỏ → thêm transistor |
| MQTT HiveMQ | Publish/Subscribe | PASS | – |
| RTC DS3231 | – | ⏳ | Test ở W6 (bước B4 bring-up) |

## Tuần 5 – Hiện thực
**Câu hỏi trung tâm:** *Xây được các module đã thiết kế chưa?*

| Kết quả | Minh chứng |
|---|---|
| Firmware v1: đọc DS18B20, hysteresis chiller, servo cho ăn + tạm dừng bơm, OLED, Self-Test, MQTT 2 chiều | `smart_aquarium_esp32s3.ino` (v1) |
| Web dashboard v1 (Tailwind + MQTT.js + Chart.js) deploy Vercel | `Index1.html`, link Vercel `…` |
| Hướng dẫn nạp code, đẩy GitHub, deploy | `README.md` |
| **Lỗi còn tồn tại (đã phân tích ở W6):** vòng lặp blocking (`delay`, `requestTemperatures`), MANUAL không tự về AUTO, biểu đồ web lỗi `datasets.data`, backend `localhost` không gọi được từ Vercel, bộ đếm cho ăn mất khi reset | `docs/04_PHAN_CUNG_REV2_RTC.md`, commit W6 |

## Tuần 6 – Tích hợp hệ thống (tuần hiện tại)
**Câu hỏi trung tâm:** *Các module có làm việc cùng nhau không?*

| Hạng mục | Người phụ trách | Trạng thái | Minh chứng |
|---|---|---|---|
| Rà soát toàn bộ mạch Rev1, lập danh sách 13 lỗi/cải tiến | Rel | ✅ | `docs/04` §1 |
| Mạch Rev2: giữ nguyên chân cũ (relay 19/18, còi 12), thêm chân RTC/quạt/nút; nguồn 12V-10A + cầu chì, JD-VCC relay, MOSFET quạt, transistor còi, tụ servo | Rel | ✅ thiết kế · 🔄 hàn PCB | `docs/04` §3–6 |
| **Tích hợp RTC DS3231** (I2C chung OLED + SQW GPIO7) | Rel | ✅ thiết kế + FW · 🔄 test phần cứng | `docs/04` §4.5, §8 |
| Firmware v2.0.0: non-blocking, RTC/NTP, lịch cho ăn, an toàn, NVS, LWT | Rel + TV2 | ✅ code · 🔄 nạp & chạy thật | `firmware/…ino` |
| Web v2: sửa biểu đồ, hiển thị giờ RTC, lịch, ngưỡng, cảnh báo, đồng bộ giờ | TV3 | ✅ code · 🔄 deploy | `index.html` |
| Cập nhật BOM v1.1 | Rel | ✅ | `hardware/danh_sach_mua_sam_v1.1.xlsx` |
| Đặc tả hệ thống v2.0 | TV4 + Rel | ✅ | `docs/02` |
| Report Chương 1 & 2 | TV4 + cả nhóm | ✅ | `report/Report_Chuong1_2.docx` |
| Test end-to-end: Web → MQTT → relay → OLED | Cả nhóm | ⏳ sau khi hàn xong | video demo `…` |

**Use case tích hợp phải demo cuối W6:**
1. Ngâm cảm biến vào nước ấm 28°C → sò + quạt bật → OLED `LANH:ON` → Web cập nhật ≤ 2 s.
2. Tắt router → đến mốc lịch → servo cho ăn, bơm tạm dừng rồi chạy lại → OLED `An:1/ngay`.
3. Rút dây DS18B20 → sò tắt, còi kêu, Web hiện cảnh báo `Mất cảm biến`.

**Vướng mắc / rủi ro:** chờ linh kiện bổ sung (relay, bơm, nguồn 10A); cần đo năng lực làm lạnh thực tế của sò với bể 4.5 L ở W7.

---

## Mẫu cập nhật cho tuần tiếp theo (copy khi sang W7)

```markdown
## Tuần N – <Giai đoạn>
**Câu hỏi trung tâm:** …
| Hạng mục | Người phụ trách | Trạng thái | Minh chứng |
|---|---|---|---|
**Kết quả chính:** …
**Vướng mắc:** …
**Kế hoạch tuần sau:** …
```

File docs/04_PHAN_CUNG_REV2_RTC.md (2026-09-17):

# 04 – PHẦN CỨNG REV2: LÀM LẠI TOÀN BỘ MẠCH + TÍCH HỢP RTC DS3231

> **Người phụ trách:** Rel (TV1 – Hardware) · **Tuần:** W6 – System Integration
> **Mục tiêu:** Hoàn thiện toàn bộ mạch trên PCB đục lỗ, sửa các lỗi thiết kế của Rev1 và thêm module thời gian thực DS3231 (đã có trong danh sách mua sắm) để lịch cho cá ăn chạy đúng giờ kể cả khi mất Wi-Fi / mất điện.
> **Firmware đi kèm:** `firmware/smart_aquarium_esp32s3/smart_aquarium_esp32s3.ino` (v2.0.0)

---

## 1. Kết quả rà soát Rev1 – cần LÀM LẠI những gì?

Mức độ: 🔴 bắt buộc sửa (có thể hỏng linh kiện / sai chức năng) · 🟠 nên sửa (không ổn định) · 🟢 cải tiến

| # | Mức | Vấn đề ở Rev1 | Hậu quả | Cách làm lại ở Rev2 |
|---|---|---|---|---|
| H1 | 🔴 | Trở kéo DS18B20 **lên 5V** (README + bảng nối chân) | Chân GPIO ESP32-S3 **không chịu 5V** → hỏng dần GPIO4 | Cấp DS18B20 bằng **3V3**, trở 4.7 kΩ nối DQ ↔ **3V3** |
| H2 | 🟢 | Relay Chiller ở **GPIO19** (trùng USB D−) | Mạch cũ đã chạy ổn | **Giữ nguyên GPIO19/GPIO18**; chỉ lưu ý nạp code qua cổng **UART/COM** của DevKit |
| H3 | 🔴 | Nguồn **12V–5A** cho cả hệ | TEC1-12706 tự ăn ~5–6 A @12V + quạt + bơm + buck 5V ≈ **7 A** → adapter quá tải, sụt áp, nóng | Đổi nguồn **12V – 10A** (120 W) + cầu chì 10 A đầu vào |
| H4 | 🟢 | Relay module 5V kích bằng GPIO 3.3V | Relay đang chạy ổn → **giữ nguyên cách nối cũ** | Chỉ khi đèn IN không tắt hẳn: tháo jumper JD-VCC (`VCC=3V3`, `JD-VCC=5V`) |
| H5 | 🔴 | OLED & DS3231 cấp 5V | Module có sẵn trở kéo I2C lên VCC → SDA/SCL bị kéo lên **5V** vào ESP32 | Cấp **OLED + DS3231 = 3V3** (cả hai chạy tốt 3.3V) |
| H6 | 🟢 | Còi nối thẳng GPIO12 | Còi hơi nhỏ | **Giữ GPIO12**; muốn to hơn thì thêm transistor S8050 (tùy chọn) |
| H7 | 🟠 | Quạt chung relay với sò | Tắt sò là tắt quạt ngay → nhiệt mặt nóng dội ngược sang mặt lạnh | Quạt tách riêng qua **MOSFET IRLZ44N** (đã có trong BOM) + chạy trễ 60 s |
| H8 | 🟠 | Servo không có tụ đệm | Dòng khởi động servo kéo tụt 5V → `BROWNOUT_RST` | Tụ **1000 µF/16V + 100 nF** sát jack servo |
| H9 | 🟠 | Không có cầu chì, dây lực đi trên PCB đục lỗ | Đường đồng lỗ chịu dòng kém → cháy mạch khi dòng 6 A | Dây Peltier **≥ 1 mm² (18 AWG)** đi thẳng qua **domino KF301**, không đi trên đường lỗ |
| H10 | 🟠 | Driver OLED: code dùng SSD1306 nhưng OLED 1.3" gần như luôn là **SH1106** | Lệch 2 cột, nhiễu mép màn | Firmware v2 dùng `Adafruit_SH110X` (có `#define` chuyển lại SSD1306) |
| H11 | 🟠 | BOM ≠ thiết kế: BOM ghi **TFT ST7789 SPI**, thiếu **relay 2 kênh** và **máy bơm 12V** | Mua sai / thiếu linh kiện | Cập nhật `hardware/danh_sach_mua_sam_v1.1.xlsx` |
| H12 | 🟢 | Chưa có thời gian thực | Lịch cho ăn phụ thuộc Internet; mất điện là mất giờ | **Thêm RTC DS3231** trên bus I2C chung + chân SQW ngắt 1 Hz |
| H13 | 🟢 | Chỉ có nút BOOT | Không cho ăn tại chỗ được | Thêm **nút FEED** GPIO16 |

---

## 2. Sơ đồ khối phần cứng Rev2

```mermaid
flowchart LR
  PSU["Adapter 12V-10A"] --> FUSE["Cầu chì 10A"]
  FUSE --> R12["Thanh nguồn 12V"]
  R12 --> BUCK["Buck LM2596 → 5.0V"]
  R12 -->|"qua tiếp điểm Relay CH1"| TEC["Sò TEC1-12706"]
  R12 -->|"qua tiếp điểm Relay CH2"| PUMP["Bơm 12V"]
  R12 -->|"qua MOSFET IRLZ44N"| FAN["Quạt 12V"]
  BUCK --> R5["Thanh 5V"]
  R5 --> ESP["ESP32-S3 DevKitC (chân 5V)"]
  R5 --> SERVO["Servo MG90S + tụ 1000µF"]
  R5 --> RLYCOIL["Relay JD-VCC"]
  R5 --> BUZ["Còi (qua S8050)"]
  ESP -->|"LDO 3V3"| R33["Thanh 3V3"]
  R33 --> OLED["OLED 1.3 SH1106 0x3C"]
  R33 --> RTC["DS3231 0x68 + CR2032"]
  R33 --> DS["DS18B20 + 4.7k"]
  R33 --> RLYVCC["Relay VCC (opto)"]
```

---

## 3. Bảng nối chân Rev2 (so với Rev1)

| Chức năng | Rev1 | **Rev2** | Ghi chú điện |
|---|---|---|---|
| DS18B20 DQ | GPIO4 | **GPIO4** | VDD = **3V3**, trở 4.7 kΩ DQ↔3V3 |
| I2C SDA (OLED + RTC) | GPIO8 | **GPIO8** | Bus chung, OLED 0x3C, DS3231 0x68, EEPROM AT24C32 0x57 |
| I2C SCL | GPIO9 | **GPIO9** | Tốc độ 400 kHz, dây ≤ 20 cm |
| **DS3231 SQW/INT** | – | **GPIO7** | INPUT_PULLUP, xung 1 Hz → ngắt FALLING |
| Relay CH1 – Sò Peltier | GPIO19 | **GPIO19 (giữ nguyên)** | Active-LOW |
| Relay CH2 – Bơm | GPIO18 | **GPIO18 (giữ nguyên)** | Active-LOW |
| **Quạt tản nhiệt** | chung relay | **GPIO15** | Gate IRLZ44N qua 100 Ω, kéo xuống 10 kΩ |
| Servo MG90S | GPIO13 | **GPIO13** | PWM 50 Hz, 500–2400 µs |
| Còi | GPIO12 | **GPIO12 (giữ nguyên)** | Nối thẳng như cũ (S8050 tùy chọn) |
| Nút Self-Test | GPIO0 (BOOT) | **GPIO0** | Giữ 2 s |
| **Nút FEED** | – | **GPIO16** | Nút → GND, INPUT_PULLUP |

**Chân nên tránh khi thêm mới trên ESP32-S3 N8R8/N16R8:** GPIO20 (USB; GPIO19 đang dùng cho relay – nạp code qua cổng UART), GPIO26–32 (SPI Flash), GPIO33–37 (PSRAM Octal), GPIO3/45/46 (strapping), GPIO43/44 (UART0 – nạp code/Serial).

---

## 4. Chi tiết đấu nối từng khối

### 4.1 Khối nguồn

```text
Adapter 12V-10A (+) ──[Cầu chì 10A]──┬──────────────── 12V BUS (dây 1mm²)
                                      │
                                      ├── LM2596 IN+      LM2596 OUT+ ── 5V BUS
Adapter (−) ─────────────────────────┴── LM2596 IN−      LM2596 OUT− ── GND CHUNG (hình sao)
                         Tụ 470µF/25V trên 12V BUS    Tụ 470µF/10V trên 5V BUS
```

1. **Vặn biến trở LM2596 ra 5.0–5.1 V khi CHƯA cắm tải** (đo bằng đồng hồ).
2. GND nối **hình sao** tại một điểm gần buck: GND dòng lớn (sò, bơm, quạt) không đi chung đường với GND logic (ESP32, cảm biến).
3. ⚠️ Không cắm **cáp USB và 5V ngoài cùng lúc** nếu chưa có diode chống ngược. Khi nạp code: rút jack 5V ngoài **hoặc** thêm diode Schottky 1N5819/SS34 nối tiếp từ 5V BUS → chân 5V của DevKit.
4. LM2596 thực tế chỉ nên tải liên tục ~2 A. Tải 5V của hệ ≈ 1.3 A đỉnh → vẫn đạt. Nếu nóng: thay **XL4015 (5 A)**.

### 4.2 Relay 2 kênh (sò + bơm)

> Relay đang chạy ổn thì **giữ nguyên dây như mạch cũ** (IN1→GPIO19, IN2→GPIO18, VCC/GND như cũ). Cách tách JD-VCC dưới đây chỉ dùng khi đèn IN không tắt hẳn.

```text
Relay module:  [JD-VCC] [VCC]  ← THÁO JUMPER nối 2 chân này
               JD-VCC ─── 5V BUS    (nuôi cuộn relay)
               VCC    ─── 3V3       (nuôi LED opto, cùng mức với GPIO)
               GND    ─── GND chung
               IN1    ─── GPIO19    IN2 ─── GPIO18

Tiếp điểm CH1:  COM ── 12V BUS     NO ── (+) Sò TEC1-12706     (−) Sò ── GND 12V
Tiếp điểm CH2:  COM ── 12V BUS     NO ── (+) Bơm 12V           (−) Bơm ── GND 12V
```

- Dùng tiếp điểm **NO** (thường mở): mất điện/ESP32 treo → sò & bơm **tắt** (an toàn). Riêng bơm có thể chuyển sang **NC** nếu nhóm muốn "mất ESP32 vẫn lọc nước" → khi đó phải đảo logic `RELAY_ON/OFF` cho CH2 trong firmware.
- Firmware set mức OFF **trước** `pinMode(OUTPUT)` để relay không chớp khi khởi động.

### 4.3 Quạt tản nhiệt qua MOSFET IRLZ44N

```text
GPIO15 ──[100Ω]──┬── G (IRLZ44N)
                 └─[10kΩ]── GND
Quạt (+) ── 12V BUS          D ── Quạt (−)          S ── GND
Diode 1N5819: Anode → D (Quạt −), Cathode → 12V (song song ngược với quạt)
```

### 4.4 DS18B20 (chống nước, 3 dây)

```text
Đỏ  (VDD) ── 3V3
Đen (GND) ── GND
Vàng (DQ) ── GPIO4 ──[4.7kΩ]── 3V3      (+ tụ 100nF VDD–GND sát domino)
```

### 4.5 Bus I2C: OLED 1.3" SH1106 + RTC DS3231

```text
                3V3 ──┬───────────────┬───────────────
                      │               │
               OLED VCC         DS3231 VCC
GPIO8 (SDA) ──── OLED SDA ────── DS3231 SDA
GPIO9 (SCL) ──── OLED SCL ────── DS3231 SCL
GPIO7       ─────────────────── DS3231 SQW
GND ──────────── OLED GND ────── DS3231 GND
                                  DS3231 32K: bỏ trống
```

**Lưu ý riêng cho module DS3231 ZS-042 (loại phổ biến có EEPROM AT24C32):**
- Module có mạch "sạc pin" (điện trở 200 Ω + diode 1N4148) cho pin **LIR2032 sạc được**. Nếu dùng **CR2032 (không sạc)** như trong BOM → **gỡ điện trở 200 Ω hoặc diode** để tránh sạc vào pin (nguy cơ phồng pin). Cấp VCC 3.3V giúp giảm rủi ro nhưng vẫn nên gỡ.
- Hai module đều có trở kéo I2C → điện trở song song ≈ 2.35 kΩ, vẫn trong ngưỡng I2C 400 kHz.
- Địa chỉ không trùng: OLED 0x3C, DS3231 0x68, EEPROM 0x57.

### 4.6 Servo MG90S

```text
Nâu ── GND        Đỏ ── 5V BUS        Cam ── GPIO13
Tụ 1000µF/16V + 100nF song song ngay tại header servo
```

### 4.7 Còi active 5V + nút nhấn

```text
5V ── Còi(+)   Còi(−) ── C (S8050)   E ── GND   B ──[1kΩ]── GPIO12
GPIO16 ── Nút FEED ── GND           GPIO0 = nút BOOT có sẵn trên DevKit
```

---

## 5. Ngân sách công suất

| Tải | Điện áp | Dòng (điển hình / đỉnh) | Quy về 12V |
|---|---|---|---|
| Sò TEC1-12706 | 12 V | ~5.0 / 6.4 A | 6.4 A |
| Quạt tản nhiệt | 12 V | 0.2 / 0.3 A | 0.3 A |
| Bơm lọc mini | 12 V | 0.3 / 0.8 A | 0.8 A |
| ESP32-S3 (Wi-Fi TX) | 5 V | 0.1 / 0.35 A | |
| Servo MG90S | 5 V | 0.15 / 0.7 A | |
| Relay ×2 + OLED + RTC + còi | 5V/3V3 | ~0.2 A | |
| **Tổng nhánh 5V** | 5 V | **≈ 1.3 A đỉnh** | ≈ 0.65 A (η≈85%) |
| **TỔNG** | | | **≈ 8.2 A đỉnh** → chọn **12V – 10A** |

---

## 6. Bố trí trên PCB đục lỗ 7×9 cm (gợi ý)

```text
┌──────────────────────────── 90 mm ────────────────────────────┐
│ [KF301 12V IN] [FUSE]  │ VÙNG CÔNG SUẤT 12V                     │
│ [KF301 SÒ] [KF301 BƠM] │ (module relay đặt ngoài PCB, bắt vít)  │
│ [KF301 QUẠT] IRLZ44N+D │ Dây lực đi dây rời, không qua lỗ đồng  │
├────────────────────────┼────────────────────────────────────────┤
│ LM2596 (bắt trụ đồng)  │ VÙNG LOGIC 5V / 3V3                     │
│ tụ 470µF   S8050+còi   │ [Header cái ESP32-S3 DevKitC 2×22]      │
│ [Header SERVO + 1000µF]│ [JST OLED] [JST DS3231] [KF301 DS18B20] │
│ [Nút FEED]             │ 4.7k, 10k, 100Ω, 100nF                 │
└────────────────────────────────────────────────────────────────┘
```

- Hàn **header cái** cho ESP32 để tháo ra nạp/sửa được.
- Dùng connector (JST-XH / domino) cho mọi linh kiện ngoài: dễ tháo khi test từng module.
- Đi dây GND logic và GND công suất về chung **một điểm** gần buck.

---

## 7. Quy trình lắp & bring-up (làm theo thứ tự, test xong mới sang bước kế)

| Bước | Việc làm | Đo / kiểm tra | Đạt khi |
|---|---|---|---|
| B1 | Hàn khối nguồn (fuse, buck, tụ), **chưa gắn ESP32** | Đo 12V BUS, 5V BUS | 12.0±0.5 V · 5.0–5.1 V |
| B2 | Kiểm tra ngắn mạch | Đo trở 12V–GND, 5V–GND, 3V3–GND | > 1 kΩ |
| B3 | Gắn ESP32 (chưa ngoại vi), cấp 5V ngoài | Đo chân 3V3 | 3.3 V, board boot, Serial chạy |
| B4 | Nối I2C: OLED + DS3231 | Chạy I2C scanner | Thấy **0x3C, 0x57, 0x68** |
| B5 | Nối DS18B20 | Serial đọc nhiệt | Khác −127/85, sai lệch ≤0.5°C so với nhiệt kế |
| B6 | Nối relay (tháo JD-VCC), **chưa nối tải 12V** | Toggle GPIO19/18 | LED + tiếng "tách" đúng, OFF là **tắt hẳn** |
| B7 | Nối quạt qua MOSFET | GPIO15 HIGH/LOW | Quạt chạy/dừng, MOSFET không nóng |
| B8 | Nối servo + tụ | Chạy sweep 0→110→0 | Không reset (không `BROWNOUT_RST`) |
| B9 | Nối bơm + sò (tải thật) | Ampe kìm/đồng hồ trên 12V | Tổng dòng ≤ 8 A, adapter không sụt < 11.5 V |
| B10 | Nạp firmware v2, chạy Self-Test (giữ BOOT 2 s) | OLED + Web | 6 mục PASS |

---

## 8. Kiểm thử tích hợp RTC (test case cho W6–W7)

| TC | Mục tiêu | Cách làm | Kỳ vọng |
|---|---|---|---|
| TC-RTC-01 | Nhận diện RTC | Khởi động, xem OLED góc phải | Hiển thị `R+` |
| TC-RTC-02 | Đồng bộ NTP → RTC | Có Wi-Fi, chờ ≤ 1 phút | Web: `time_src = NTP`, event `time_sync` |
| TC-RTC-03 | Giữ giờ khi mất điện | Rút nguồn 10 phút → cắm lại **không Wi-Fi** | Giờ đúng (lệch ≤ 2 s), `time_src = RTC` |
| TC-RTC-04 | Cho ăn đúng lịch khi offline | Đặt lịch = giờ hiện tại +2 phút, tắt router | Servo chạy đúng phút đó, `feed_today` +1 |
| TC-RTC-05 | Không cho ăn 2 lần sau reset | Reset ESP32 ngay sau khi cho ăn theo lịch | Không cho ăn lại (NVS lưu `lastSched`) |
| TC-RTC-06 | Cho ăn bù | Rút điện qua mốc lịch, cắm lại trong 30 phút | Cho ăn bù 1 lần |
| TC-RTC-07 | Chống cho ăn dày | Bấm FEED, 5 phút sau tới mốc lịch | Bỏ qua mốc, event `feed_skip` |
| TC-RTC-08 | Đặt giờ từ Web | Không NTP, bấm "Đồng bộ giờ từ trình duyệt" | RTC nhận giờ, `time_src = WEB` |
| TC-RTC-09 | Pin RTC hết/không gắn | Tháo CR2032, mất điện, không Wi-Fi | Cảnh báo `TIME_INVALID`, lịch tạm dừng, không cho ăn sai giờ |
| TC-RTC-10 | Ngắt SQW | Rút dây SQW | Firmware tự chuyển nhịp dự phòng `millis()`, lịch vẫn chạy |

---

## 9. Linh kiện cần mua bổ sung / thay đổi

| Linh kiện | SL | Lý do |
|---|---|---|
| Module Relay 2 kênh 5V có jumper JD-VCC (opto PC817) | 1 | Thiếu trong BOM v1.0 |
| Máy bơm mini 12V (bơm chìm hoặc bơm màng 385) | 1 | Thiếu trong BOM v1.0 |
| Nguồn 12V **10A** (thay 12V-5A) | 1 | Ngân sách công suất |
| Màn hình OLED 1.3" I2C SH1106 (thay TFT ST7789) | 1 | Đồng bộ với firmware & bus I2C chung RTC |
| Cầu chì 10A + đế cầu chì | 1 | Bảo vệ quá dòng |
| Transistor S8050, diode 1N5819 ×2, tụ 1000µF/16V, tụ 470µF ×2, 100nF ×5 | bộ | Driver còi, chống ngược, lọc nguồn |
| Domino KF301 2P ×6, header cái 2×22, JST-XH 4P ×3 | bộ | Connector tháo lắp |
| Nút nhấn 6×6 mm | 1 | Nút FEED |
| Dây điện 1 mm² (đỏ/đen) 1 m | 1 | Đường lực Peltier |

*(Chi tiết giá tham khảo trong `hardware/danh_sach_mua_sam_v1.1.xlsx` – cần kiểm tra lại giá thực tế trước khi mua.)*

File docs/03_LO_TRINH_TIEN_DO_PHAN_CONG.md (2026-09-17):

# 03 – LỘ TRÌNH · TIẾN ĐỘ · PHÂN CÔNG NHIỆM VỤ

> Cập nhật: 17/09/2026 (W6). **Điền tên / MSSV / SĐT thật của thành viên** vào bảng dưới (thầy yêu cầu nộp kèm danh sách).

## 1. Thành viên & vai trò

| Mã | Họ tên | MSSV | SĐT | Vai trò chính |
|---|---|---|---|---|
| TV1 | Rel | … | … | **Hardware lead**: toàn bộ mạch, nguồn, PCB, tích hợp RTC DS3231 |
| TV2 | … | … | … | Firmware: driver, logic điều khiển, test đơn vị |
| TV3 | … | … | … | Web dashboard, MQTT, deploy Vercel |
| TV4 | … | … | … | Tài liệu, report, test case, slide; đại diện nộp UTEXLMS |

*(Nhóm 3 người: gộp TV3 + TV4.)*

---

## 2. Lộ trình 9 tuần

| Tuần | Thời gian (dự kiến) | Giai đoạn | Output | Phụ trách chính | Tiến độ |
|---|---|---|---|---|---|
| W1 | 10/08 – 16/08 | Requirement Analysis | Bảng phân tích yêu cầu | Cả nhóm | ✅ 100% |
| W2 | 17/08 – 23/08 | System Specification | Đặc tả FR/NFR | TV4 | ✅ 100% |
| W3 | 24/08 – 30/08 | Architecture & HW/SW | Sơ đồ khối, pinout, BOM | TV1, TV2 | ✅ 100% (sửa ở W6) |
| W4 | 31/08 – 06/09 | Prototype Validation | Kết quả test module | TV1, TV2 | ✅ 90% (RTC dời sang W6) |
| W5 | 07/09 – 13/09 | Implementation | FW v1, Web v1 | TV2, TV3 | ✅ 100% |
| **W6** | **14/09 – 20/09** | **System Integration** | **Mạch Rev2 + RTC, FW v2, Web v2, Report Ch.1–2** | **TV1 (mạch), cả nhóm** | 🔄 **~60%** |
| W7 | 21/09 – 27/09 | Testing & Optimization | Bảng test case PASS/FAIL, bản sửa lỗi | TV4, TV2 | ⏳ |
| W8 | 28/09 – 04/10 | Finalization | Prototype hoàn chỉnh, Report đủ chương, Slide | Cả nhóm | ⏳ |
| W9 | 05/10 – 11/10 | Evaluation | Demo + bảo vệ | Cả nhóm | ⏳ |

```mermaid
gantt
  dateFormat YYYY-MM-DD
  title Smart Aquarium – 9 tuần
  section Design
  W1 Requirement      :done, 2026-08-10, 7d
  W2 Specification    :done, 2026-08-17, 7d
  W3 Architecture     :done, 2026-08-24, 7d
  section Build
  W4 Validation       :done, 2026-08-31, 7d
  W5 Implementation   :done, 2026-09-07, 7d
  W6 Integration      :active, 2026-09-14, 7d
  section Final
  W7 Testing          :2026-09-21, 7d
  W8 Finalization     :2026-09-28, 7d
  W9 Evaluation       :2026-10-05, 7d
```

---

## 3. Bảng công việc chi tiết Tuần 6

| ID | Công việc | Người làm | Deadline | Phụ thuộc | Trạng thái | Output |
|---|---|---|---|---|---|---|
| W6-01 | Rà soát mạch Rev1, liệt kê lỗi | **Rel** | 15/09 | – | ✅ | `docs/04` §1 |
| W6-02 | Thiết kế Rev2: pinout, nguồn, driver | **Rel** | 16/09 | W6-01 | ✅ | `docs/04` §3–5 |
| W6-03 | Cập nhật BOM v1.1, đặt mua linh kiện thiếu | **Rel** | 16/09 | W6-02 | ✅ BOM · 🔄 chờ hàng | xlsx v1.1 |
| W6-04 | Hàn khối nguồn + test B1–B3 | **Rel** | 18/09 | W6-03 | 🔄 | Ảnh đo áp |
| W6-05 | Hàn bus I2C + gắn DS3231, OLED; test B4 | **Rel** | 18/09 | W6-04 | 🔄 | Ảnh I2C scanner |
| W6-06 | Hàn relay (JD-VCC), MOSFET quạt, servo, còi, nút; test B5–B9 | **Rel** | 19/09 | W6-05 | ⏳ | Video test |
| W6-07 | FW v2: RTC/NTP, lịch, non-blocking, an toàn | Rel + TV2 | 17/09 | – | ✅ | `.ino` v2.0.0 |
| W6-08 | Nạp FW v2 lên mạch Rev2, Self-Test | TV2 + Rel | 19/09 | W6-06, W6-07 | ⏳ | Ảnh OLED PASS |
| W6-09 | Web v2 + deploy Vercel, khớp TOPIC_BASE | TV3 | 18/09 | W6-07 | 🔄 | Link Vercel |
| W6-10 | Test 3 use case end-to-end + TC-RTC-01..04 | Cả nhóm | 20/09 | W6-08, W6-09 | ⏳ | Video demo |
| W6-11 | Đặc tả v2.0 | TV4 + Rel | 17/09 | – | ✅ | `docs/02` |
| W6-12 | Report Chương 1, 2 | TV4 | 17/09 | W6-11 | ✅ | `.docx` |
| W6-13 | Push GitHub + nộp UTEXLMS | TV4 | 20/09 | tất cả | ⏳ | Link commit |

## 4. Kế hoạch W7 – W9

| Tuần | Công việc | Người làm |
|---|---|---|
| W7 | Chạy toàn bộ TC01–TC16 + TC-RTC-01..10, ghi PASS/FAIL, số lần lặp | TV4 (chủ trì), TV2 |
| W7 | Đo năng lực làm lạnh: log nhiệt độ 2 giờ khi phòng nóng, thời gian hạ 1°C | Rel |
| W7 | Đo dòng tổng, nhiệt độ LM2596/MOSFET sau 1 giờ chạy | Rel |
| W7 | Tối ưu: RAM/Flash, thời gian loop, độ ổn định MQTT 24 h | TV2, TV3 |
| W8 | Đóng hộp/cố định mạch, đi dây gọn, dán nhãn connector | Rel |
| W8 | Report Chương 3 (Thiết kế), 4 (Kết quả), 5 (Kết luận), User guide | TV4 + cả nhóm |
| W8 | Slide + video demo 3 phút | TV3, TV4 |
| W9 | Demo, trả lời câu hỏi thiết kế (Why/What/How/Evidence) | Cả nhóm |

## 5. Rủi ro & phương án

| Rủi ro | Mức | Phương án |
|---|---|---|
| Linh kiện bổ sung giao trễ | Cao | Mua tại cửa hàng trực tiếp; tạm test bằng nguồn 12V-5A **không nối sò** |
| Sò không đủ công suất hạ nhiệt bể | Trung bình | Cách nhiệt thành bể, tăng lưu lượng nước, dùng tản nhiệt lớn hơn; ghi nhận giới hạn trong report |
| Hở nước gần mạch điện | Cao | Mạch đặt cao hơn mặt nước, hộp nhựa, ống silicone siết cổ dê |
| Broker công cộng mất kết nối | Thấp | Hệ thống vẫn tự động hoàn toàn nhờ RTC + logic cục bộ |
| Mạch hàn lỗi khó dò | Trung bình | Hàn theo khối, test B1–B10 từng bước, dùng connector |

---

## 6. Quản lý công việc cá nhân – Rel (TV1)

> Giờ làm và kết quả dưới đây là **bản nháp – Rel sửa lại theo thực tế**. Mẫu này dùng cho file "Quản lý công việc cá nhân" cuối kỳ. Mỗi thành viên copy thành file riêng.

| Ngày | Tuần | Công việc | Thời gian | Kết quả / minh chứng | Vấn đề gặp phải |
|---|---|---|---|---|---|
| 15/09 | W6 | Rà soát mạch Rev1, đối chiếu BOM – code – tài liệu | 3 h | 13 lỗi/cải tiến (`docs/04` §1) | Phát hiện nguồn 5A không đủ, GPIO19 trùng USB |
| 16/09 | W6 | Thiết kế Rev2 + ngân sách công suất + BOM v1.1 | 3 h | `docs/04` §3–5, xlsx v1.1 | Thiếu relay & bơm trong BOM |
| 17/09 | W6 | FW v2 phần RTC/NTP, lịch cho ăn; test case RTC | 4 h | `.ino` v2.0.0, `docs/04` §8 | – |
| 18/09 | W6 | Hàn nguồn + I2C, test B1–B5 | … | … | … |
| 19/09 | W6 | Hàn khối công suất, test B6–B10 | … | … | … |

**Tổng kết đóng góp W6 (tự đánh giá):** thiết kế lại toàn bộ mạch, tích hợp RTC, đồng tác giả firmware v2.

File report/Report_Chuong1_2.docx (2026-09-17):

BỘ GIÁO DỤC VÀ ĐÀO TẠO

TRƯỜNG ĐẠI HỌC SƯ PHẠM KỸ THUẬT TP. HỒ CHÍ MINH

KHOA ………………………………

BÁO CÁO BÀI TẬP LỚN

MÔN HỌC: THIẾT KẾ HỆ THỐNG NHÚNG (EMBEDDED SYSTEM DESIGN)

ĐỀ TÀI:

THIẾT KẾ HỆ THỐNG BỂ CÁ THÔNG MINH IoT

TỰ ĐỘNG LÀM MÁT VÀ CHO CÁ ĂN THEO THỜI GIAN THỰC

SỬ DỤNG VI ĐIỀU KHIỂN ESP32-S3

GVHD: Huỳnh Hoàng Hà

Nhóm sinh viên thực hiện:

1. Rel – MSSV: ……………

2. ……………… – MSSV: ……………

3. ……………… – MSSV: ……………

4. ……………… – MSSV: ……………

TP. Hồ Chí Minh, tháng 9 năm 2026

MỤC LỤC

(Mở bằng Word → nhấp chuột phải vào mục lục → Update Field để cập nhật số trang.)

DANH MỤC TỪ VIẾT TẮT

Từ viết tắt | Tiếng Anh | Nghĩa tiếng Việt
IoT | Internet of Things | Internet vạn vật
MCU | Microcontroller Unit | Vi điều khiển
RTC | Real-Time Clock | Đồng hồ thời gian thực
TCXO | Temperature-Compensated Crystal Oscillator | Bộ dao động thạch anh bù nhiệt
NTP / SNTP | (Simple) Network Time Protocol | Giao thức đồng bộ thời gian qua mạng
MQTT | Message Queuing Telemetry Transport | Giao thức truyền thông điệp publish/subscribe
QoS | Quality of Service | Mức chất lượng dịch vụ
LWT | Last Will and Testament | Thông điệp "di chúc" khi mất kết nối
I2C | Inter-Integrated Circuit | Bus giao tiếp nối tiếp 2 dây
PWM | Pulse Width Modulation | Điều chế độ rộng xung
TEC | Thermoelectric Cooler | Phần tử làm lạnh nhiệt điện (sò Peltier)
OLED | Organic Light-Emitting Diode | Điốt phát quang hữu cơ
FR / NFR | Functional / Non-Functional Requirement | Yêu cầu chức năng / phi chức năng
NVS | Non-Volatile Storage | Bộ nhớ không bay hơi
GPIO | General-Purpose Input/Output | Chân vào/ra đa dụng

# CHƯƠNG 1: TỔNG QUAN ĐỀ TÀI

## 1.1. Đặt vấn đề

Nuôi cá cảnh trong bể mini (dưới 10 lít) ngày càng phổ biến tại các căn hộ, phòng trọ và bàn làm việc nhờ chi phí thấp và không chiếm nhiều diện tích. Tuy nhiên, chính thể tích nước nhỏ lại là điểm yếu lớn nhất của loại bể này: nhiệt dung của khối nước thấp nên nhiệt độ nước thay đổi nhanh theo nhiệt độ phòng. Ở TP. Hồ Chí Minh, vào mùa nắng nóng, nhiệt độ trong phòng không có điều hòa có thể lên đến 32–35°C, trong khi phần lớn các loài cá cảnh nhiệt đới phổ biến chỉ sinh trưởng tốt trong khoảng 24–28°C. Nước quá nóng làm giảm lượng oxy hòa tan, tăng tốc độ trao đổi chất và khiến cá dễ bị stress, mắc bệnh; sự thay đổi nhiệt độ đột ngột còn có thể gây sốc nhiệt.

Bên cạnh đó, việc cho cá ăn đúng giờ và đúng lượng là một thói quen khó duy trì khi người nuôi bận rộn hoặc vắng nhà vài ngày. Cho ăn không đều khiến cá suy yếu, còn cho ăn quá nhiều làm thức ăn thừa phân hủy, gây ô nhiễm nước – một vấn đề càng nghiêm trọng với bể nhỏ. Các máy cho ăn tự động giá rẻ trên thị trường thường chỉ hẹn giờ đơn giản, mất cài đặt khi mất điện và không cho biết tình trạng bể từ xa.

Từ thực tế trên, nhóm lựa chọn đề tài “Thiết kế hệ thống bể cá thông minh IoT tự động làm mát và cho cá ăn theo thời gian thực sử dụng vi điều khiển ESP32-S3”. Đề tài vừa giải quyết một nhu cầu thực tế, vừa bao quát đầy đủ các thành phần của một hệ thống nhúng điển hình: cảm biến, cơ cấu chấp hành công suất, hiển thị tại chỗ, đồng hồ thời gian thực, truyền thông không dây và giao diện người dùng từ xa – phù hợp để áp dụng trọn vẹn quy trình thiết kế hệ thống nhúng của môn học.

## 1.2. Mục tiêu đề tài

Mục tiêu tổng quát là thiết kế, chế tạo và kiểm chứng một nguyên mẫu (prototype) hệ thống điều khiển cho bể cá mini thể tích khoảng 4,5 lít (20 × 14 × 16 cm), hoạt động tự chủ tại chỗ và có khả năng giám sát, điều khiển từ xa. Các mục tiêu cụ thể gồm:

- Tự động ổn định nhiệt độ nước: đo nhiệt độ liên tục và điều khiển bộ làm mát bằng sò nóng lạnh Peltier theo luật ON/OFF có trễ, duy trì nhiệt độ trong khoảng 25,5–27,0°C.
- Tự động cho cá ăn theo lịch thời gian thực: tối đa 4 mốc giờ mỗi ngày, vẫn hoạt động đúng giờ khi mất kết nối Internet hoặc sau khi mất điện nhờ module RTC DS3231 có pin dự phòng; tạm dừng bơm lọc trong lúc cho ăn để thức ăn không bị hút mất.
- Hiển thị và thao tác tại chỗ: màn hình OLED hiển thị thời gian, nhiệt độ, trạng thái thiết bị, lần cho ăn kế tiếp và cảnh báo; nút nhấn cho ăn thủ công và tự kiểm tra phần cứng.
- Giám sát và điều khiển từ xa: truyền dữ liệu hai chiều thời gian thực giữa ESP32-S3 và Web Dashboard thông qua giao thức MQTT.
- Đảm bảo an toàn: phát hiện lỗi cảm biến, nhiệt độ vượt ngưỡng, chống cho ăn lặp/quá mức và đảm bảo các mức điện áp tín hiệu phù hợp với vi điều khiển.

## 1.3. Đối tượng và phạm vi nghiên cứu

### 1.3.1. Đối tượng nghiên cứu

- Vi điều khiển ESP32-S3 và môi trường lập trình Arduino-ESP32.
- Cảm biến nhiệt độ DS18B20, đồng hồ thời gian thực DS3231, màn hình OLED I2C.
- Phần tử làm lạnh nhiệt điện TEC1-12706, relay, MOSFET, động cơ servo MG90S, mạch nguồn buck.
- Giao thức MQTT, NTP và ứng dụng web giám sát.

### 1.3.2. Phạm vi và giới hạn

Bảng 1.1. Phạm vi và giới hạn của đề tài

Trong phạm vi đề tài | Ngoài phạm vi (hướng phát triển)
Làm mát nước bằng sò Peltier và khối tản nhiệt nước | Sưởi ấm nước khi nhiệt độ phòng thấp
Đo nhiệt độ nước tại một điểm | Đo pH, TDS, oxy hòa tan, mực nước
Cho ăn thức ăn dạng hạt khô bằng hộc xoay | Định lượng thức ăn chính xác theo khối lượng
Bể mini khoảng 4,5 lít | Bể có thể tích lớn
Truyền thông qua MQTT broker công cộng (phục vụ học tập) | Broker riêng, mã hóa TLS, xác thực người dùng
Lưu cấu hình và bộ đếm trong bộ nhớ NVS của ESP32 | Cơ sở dữ liệu lịch sử dài hạn, phân tích dữ liệu bằng AI

## 1.4. Phân tích yêu cầu hệ thống

Theo quy trình thiết kế hệ thống nhúng, bước đầu tiên là hiểu bài toán và nhu cầu người dùng trước khi lựa chọn linh kiện. Nhóm phân tích các tình huống sử dụng (use case), đặt câu hỏi phân tích và đề xuất giải pháp ở mức khối chức năng như Bảng 1.2.

Bảng 1.2. Bảng phân tích yêu cầu (Requirement Analysis)

Vấn đề / Use case | Nhu cầu người dùng | Câu hỏi phân tích | Giải pháp đề xuất
Nước nóng lên theo nhiệt độ phòng | Nhiệt độ nước luôn an toàn cho cá | Làm mát bằng gì? Khi nào bật/tắt? | Cảm biến nhiệt chống nước + bộ làm mát + điều khiển có trễ
Quên cho cá ăn | Cá được ăn đúng giờ | Mất Internet, mất điện thì sao? | Cơ cấu cho ăn + đồng hồ thời gian thực có pin + lịch lưu bộ nhớ
Cho ăn quá nhiều | Tránh ô nhiễm nước | Giới hạn như thế nào? | Khoảng cách tối thiểu giữa hai lần, giới hạn số lần/ngày
Thức ăn bị bơm lọc hút | Thức ăn không bị lọc mất | Khi nào tạm dừng bơm? | Tạm dừng bơm trong lúc cho ăn
Xem nhanh tình trạng bể | Biết nhiệt độ, trạng thái thiết bị | Hiển thị thông tin gì? | Màn hình hiển thị tại chỗ
Vắng nhà | Theo dõi, điều khiển từ xa | Qua kênh truyền nào? | Wi-Fi + giao thức IoT + giao diện web
Thiết bị hỏng âm thầm | Được cảnh báo sự cố | Phát hiện lỗi thế nào? | Kiểm tra dữ liệu cảm biến, còi, cảnh báo trên web
Lắp ráp, bảo trì | Kiểm tra nhanh phần cứng | Test không cần sửa code? | Chế độ tự kiểm tra (Self-Test)

Từ bảng phân tích, các yêu cầu chức năng chính của hệ thống được tóm tắt trong Bảng 1.3. Đặc tả chi tiết (16 yêu cầu chức năng, 8 yêu cầu phi chức năng kèm phương pháp kiểm chứng) được trình bày ở Chương 3.

Bảng 1.3. Tóm tắt yêu cầu chức năng chính

ID | Yêu cầu | Đặc tả tóm tắt
FR01 | Đo nhiệt độ | Đo nhiệt độ nước chu kỳ 1 s, sai số ≤ ±0,5°C
FR02 | Làm mát tự động | Bật làm mát khi T ≥ 27,0°C; tắt khi T ≤ 25,5°C
FR05 | Chế độ vận hành | AUTO / MANUAL; MANUAL tự trở về AUTO sau 30 phút
FR07 | Cho ăn theo lịch | Tối đa 4 mốc/ngày theo giờ RTC, không phụ thuộc Internet
FR08 | Giữ thời gian | Giữ giờ khi mất điện; đồng bộ NTP khi có mạng
FR11 | Hiển thị tại chỗ | OLED hiển thị giờ, nhiệt độ, trạng thái, cảnh báo
FR12–13 | Giám sát, điều khiển từ xa | Telemetry mỗi 2 s; nhận lệnh điều khiển qua MQTT
FR14 | Cảnh báo, an toàn | Lỗi cảm biến, quá nóng, quá lạnh → xử lý an toàn + còi

## 1.5. Nội dung thực hiện

Đề tài được triển khai theo lộ trình 9 tuần của môn học, chia thành ba giai đoạn Thiết kế – Xây dựng – Hoàn thiện, mỗi tuần có một đầu ra cụ thể (Bảng 1.4).

Bảng 1.4. Lộ trình thực hiện đề tài

Tuần | Công đoạn | Đầu ra
W1 | Phân tích yêu cầu | Bảng phân tích yêu cầu và giải pháp đề xuất
W2 | Đặc tả hệ thống | Đặc tả yêu cầu chức năng, phi chức năng, phương pháp kiểm chứng
W3 | Thiết kế kiến trúc, phân chia HW/SW | Sơ đồ khối, lựa chọn linh kiện, sơ đồ chân, dự toán
W4 | Thử nghiệm tính khả thi | Kết quả kiểm tra từng module
W5 | Hiện thực | Firmware, giao diện web, các module hoạt động
W6 | Tích hợp hệ thống | Mạch hoàn chỉnh (Rev2) tích hợp RTC, firmware v2
W7 | Kiểm thử và tối ưu | Kết quả kiểm thử theo đặc tả, hệ thống cải tiến
W8 | Hoàn thiện | Sản phẩm, báo cáo, slide trình bày
W9 | Đánh giá | Demo và bảo vệ thiết kế

## 1.6. Phương pháp nghiên cứu

- Nghiên cứu tài liệu: tìm hiểu datasheet linh kiện, tài liệu giao thức (1-Wire, I2C, MQTT, NTP) và bài giảng môn Thiết kế hệ thống nhúng.
- Thiết kế theo quy trình hệ thống nhúng: đi từ yêu cầu → đặc tả → kiến trúc → thiết kế phần cứng/phần mềm → hiện thực → tích hợp → kiểm thử, có vòng lặp điều chỉnh thiết kế khi phát hiện module không phù hợp.
- Thực nghiệm: thử nghiệm từng module độc lập, lắp ráp tăng dần theo khối (nguồn → giao tiếp → cảm biến → công suất), đo đạc điện áp, dòng điện và nhiệt độ thực tế.
- Kiểm chứng có truy vết: mỗi yêu cầu chức năng được ánh xạ tới hàm phần mềm và ca kiểm thử tương ứng.

## 1.7. Bố cục báo cáo

Báo cáo gồm 5 chương:

- Chương 1 – Tổng quan đề tài: đặt vấn đề, mục tiêu, phạm vi, phân tích yêu cầu và phương pháp thực hiện.
- Chương 2 – Cơ sở lý thuyết: các linh kiện, chuẩn giao tiếp, giao thức và thuật toán được sử dụng.
- Chương 3 – Thiết kế hệ thống: đặc tả chi tiết, kiến trúc, thiết kế phần cứng và phần mềm.
- Chương 4 – Kết quả thực hiện và kiểm thử.
- Chương 5 – Kết luận và hướng phát triển.

# CHƯƠNG 2: CƠ SỞ LÝ THUYẾT

## 2.1. Hệ thống nhúng và quy trình thiết kế

Hệ thống nhúng (embedded system) là một hệ thống máy tính chuyên dụng được tích hợp vào thiết bị để thực hiện một hoặc một vài chức năng xác định, thường có ràng buộc về thời gian đáp ứng, năng lượng, chi phí, kích thước và độ tin cậy. Một hệ thống nhúng điển hình gồm khối xử lý trung tâm (MCU/SoC), khối đầu vào (cảm biến, nút nhấn), khối đầu ra (cơ cấu chấp hành, hiển thị), bộ nhớ và khối truyền thông (UART, SPI, I2C, Wi-Fi…).

Quy trình thiết kế hệ thống nhúng áp dụng trong đề tài gồm 8 bước: (1) phân tích yêu cầu, (2) đặc tả hệ thống, (3) thiết kế kiến trúc, (4) thiết kế phần cứng, (5) thiết kế phần mềm, (6) hiện thực, (7) tích hợp và kiểm thử, (8) tối ưu và triển khai. Kiểm thử được tổ chức theo tầng từ kiểm thử đơn vị (unit test), kiểm thử module, kiểm thử driver, kiểm thử tích hợp đến kiểm thử toàn hệ thống so với yêu cầu. Nguyên tắc xuyên suốt là “hiểu bài toán trước, thiết kế trước khi xây dựng và thử nghiệm module trước khi tích hợp”.

Về phần mềm, firmware được tổ chức theo mô hình phân lớp: lớp phần cứng → lớp trừu tượng phần cứng (HAL) → driver/thư viện ngoại vi → dịch vụ (middleware) → ứng dụng. Cách tổ chức này giúp tách biệt logic điều khiển khỏi chi tiết phần cứng, dễ kiểm thử và thay thế linh kiện.

## 2.2. Vi điều khiển ESP32-S3

ESP32-S3 là dòng SoC của Espressif Systems tích hợp vi xử lý Xtensa LX7 32-bit lõi kép, Wi-Fi 2,4 GHz và Bluetooth Low Energy 5 trên cùng một chip, hướng tới các ứng dụng AIoT. Trong đề tài, nhóm sử dụng bo phát triển ESP32-S3-DevKitC-1 phiên bản N8R8/N16R8 (8/16 MB Flash, 8 MB PSRAM). Các thông số chính được trình bày ở Bảng 2.1.

Bảng 2.1. Thông số chính của ESP32-S3

Thông số | Giá trị
CPU | Xtensa LX7 32-bit lõi kép, tối đa 240 MHz
Bộ nhớ trong | 512 KB SRAM, 384 KB ROM; hỗ trợ Flash và PSRAM ngoài
Không dây | Wi-Fi 802.11 b/g/n (2,4 GHz), Bluetooth LE 5
GPIO | 45 chân GPIO lập trình được
Ngoại vi | 2 × ADC 12-bit, SPI, I2S, 2 × I2C, 3 × UART, USB OTG, LED PWM, MCPWM, TWAI, cảm ứng điện dung
Điện áp hoạt động | 3,0–3,6 V (bo DevKit có LDO 3,3 V, cấp nguồn 5 V qua USB hoặc chân 5V)

Khi thiết kế cần lưu ý một số chân có chức năng đặc biệt trên ESP32-S3: GPIO19/20 là đường USB D−/D+; GPIO26–32 kết nối bộ nhớ Flash SPI; GPIO33–37 bị chiếm bởi PSRAM giao tiếp Octal trên các module N8R8/N16R8; GPIO0, GPIO3, GPIO45, GPIO46 là chân strapping quyết định chế độ khởi động; GPIO43/44 là UART0 dùng để nạp chương trình. Đặc biệt, các chân GPIO của ESP32-S3 không chịu được mức 5 V, vì vậy mọi tín hiệu từ ngoại vi 5 V phải được giới hạn về 3,3 V.

ESP32-S3 hỗ trợ bộ nhớ không bay hơi NVS (Non-Volatile Storage) trên phân vùng Flash để lưu cặp khóa–giá trị (thư viện Preferences), cho phép lưu cấu hình và bộ đếm không bị mất khi mất điện.

## 2.3. Cảm biến nhiệt độ DS18B20 và chuẩn giao tiếp 1-Wire

### 2.3.1. Cảm biến DS18B20

DS18B20 là cảm biến nhiệt độ số của Maxim Integrated (nay thuộc Analog Devices), xuất kết quả trực tiếp dưới dạng số qua bus 1-Wire nên không cần bộ chuyển đổi ADC và ít bị ảnh hưởng bởi nhiễu trên dây dài. Phiên bản dùng trong đề tài được đóng gói trong vỏ thép không gỉ chống nước, phù hợp để ngâm trong bể cá.

Bảng 2.2. Thông số kỹ thuật DS18B20

Thông số | Giá trị
Điện áp cấp | 3,0–5,5 V (hỗ trợ chế độ cấp nguồn ký sinh)
Dải đo | −55°C đến +125°C
Độ chính xác | ±0,5°C trong khoảng −10°C đến +85°C
Độ phân giải | Lập trình 9–12 bit (0,5°C đến 0,0625°C)
Thời gian chuyển đổi | 93,75 ms (9-bit) … 375 ms (11-bit) … 750 ms (12-bit)
Định danh | Mã ROM 64-bit duy nhất, cho phép nhiều cảm biến trên một bus
Giá trị đặc biệt | +85°C sau khi bật nguồn (chưa chuyển đổi); thư viện trả −127°C khi mất kết nối

Trong đề tài, cảm biến được đặt ở độ phân giải 11-bit (0,125°C) với thời gian chuyển đổi 375 ms, và được đọc theo chế độ bất đồng bộ: vi điều khiển gửi lệnh chuyển đổi, tiếp tục xử lý công việc khác và quay lại đọc kết quả sau khoảng 400 ms, tránh làm treo vòng lặp chính. Các giá trị −127°C, 85°C hoặc nằm ngoài khoảng hợp lý 0–50°C được xem là lỗi.

### 2.3.2. Chuẩn giao tiếp 1-Wire

1-Wire là chuẩn giao tiếp bán song công chỉ dùng một đường dữ liệu (DQ) và đường mass. Đường DQ là cực máng hở (open-drain) nên cần một điện trở kéo lên (thường 4,7 kΩ) về điện áp nguồn. Thiết bị chủ (master) khởi tạo mọi giao dịch bằng xung reset (kéo thấp tối thiểu 480 µs), thiết bị tớ phản hồi bằng xung presence; sau đó dữ liệu được truyền theo các khe thời gian (time slot) mà độ rộng xung mức thấp quyết định bit 0 hay bit 1. Vì điện trở kéo lên xác định mức cao của đường DQ, khi dùng với ESP32-S3 điện trở này phải được nối lên 3,3 V.

## 2.4. Chuẩn giao tiếp I2C và màn hình OLED

### 2.4.1. Chuẩn giao tiếp I2C

I2C (Inter-Integrated Circuit) là bus nối tiếp đồng bộ do Philips (nay là NXP) phát triển, sử dụng hai dây: SDA (dữ liệu) và SCL (xung clock). Cả hai đường đều ở dạng cực máng hở và cần điện trở kéo lên. Mỗi thiết bị tớ có một địa chỉ 7-bit, nhờ đó nhiều thiết bị có thể dùng chung một bus. Một giao dịch bắt đầu bằng điều kiện START, tiếp theo là byte địa chỉ kèm bit đọc/ghi, các byte dữ liệu – mỗi byte được xác nhận bằng bit ACK – và kết thúc bằng điều kiện STOP. Các tốc độ phổ biến là 100 kbit/s (Standard mode) và 400 kbit/s (Fast mode).

Trong hệ thống, màn hình OLED (địa chỉ 0x3C), đồng hồ DS3231 (0x68) và EEPROM AT24C32 đi kèm module RTC (0x57) dùng chung một bus I2C trên GPIO8/GPIO9, giúp tiết kiệm chân vi điều khiển. Do các module thường tích hợp sẵn điện trở kéo lên về chân VCC của chính module, các module này phải được cấp nguồn 3,3 V để đường I2C không bị kéo lên 5 V.

### 2.4.2. Màn hình OLED 1,3 inch

OLED là công nghệ hiển thị trong đó mỗi điểm ảnh tự phát sáng, không cần đèn nền, nên có độ tương phản cao, góc nhìn rộng và tiêu thụ điện năng thấp khi hiển thị nội dung tối. Màn hình 1,3 inch độ phân giải 128 × 64 điểm ảnh sử dụng trong đề tài dùng chip điều khiển SH1106 với giao tiếp I2C. Bộ nhớ hiển thị của SH1106 có 132 cột, rộng hơn tấm nền 128 cột, nên phải dùng đúng thư viện cho SH1106; nếu dùng thư viện của chip SSD1306 hình ảnh sẽ bị lệch cột và xuất hiện nhiễu ở mép màn hình.

## 2.5. Đồng hồ thời gian thực DS3231 và đồng bộ thời gian NTP

### 2.5.1. Vai trò của đồng hồ thời gian thực

Bộ đếm thời gian nội của vi điều khiển (hàm millis() hoặc đồng hồ hệ thống) chỉ đếm từ lúc khởi động, bị mất khi mất điện và phụ thuộc vào thạch anh có sai số tương đối lớn theo nhiệt độ. Đối với chức năng cho cá ăn theo giờ cố định, hệ thống cần một nguồn thời gian tuyệt đối (ngày, giờ) được duy trì liên tục kể cả khi mất điện hoặc mất Internet. Đồng hồ thời gian thực (RTC) là vi mạch chuyên dụng đảm nhận nhiệm vụ này với mức tiêu thụ rất thấp và có đầu vào pin dự phòng.

### 2.5.2. Vi mạch DS3231

DS3231 là RTC giao tiếp I2C có độ chính xác cao nhờ tích hợp bộ dao động thạch anh 32 kHz có bù nhiệt (TCXO) ngay trong vỏ chip. Cảm biến nhiệt độ bên trong được dùng để định kỳ hiệu chỉnh tần số dao động, nhờ đó sai số thời gian nhỏ hơn nhiều so với các RTC dùng thạch anh ngoài như DS1307.

Bảng 2.3. Thông số kỹ thuật DS3231

Thông số | Giá trị
Độ chính xác | ±2 ppm trong khoảng 0°C đến +40°C (≈ ±1 phút/năm); ±3,5 ppm từ −40°C đến +85°C
Dữ liệu thời gian | Giây, phút, giờ, thứ, ngày, tháng, năm; tự bù năm nhuận đến năm 2100
Báo thức | 2 báo thức theo thời gian trong ngày
Ngõ ra | Chân SQW/INT: xung vuông lập trình được (1 Hz … 8,192 kHz) hoặc tín hiệu ngắt báo thức; chân 32K
Giao tiếp | I2C tốc độ tối đa 400 kHz, địa chỉ 0x68
Nguồn | VCC 2,3–5,5 V; đầu vào pin dự phòng VBAT (pin CR2032)
Cảm biến nhiệt tích hợp | Độ chính xác ±3°C

Trong đề tài, chân SQW của DS3231 được cấu hình phát xung 1 Hz và nối vào GPIO7 của ESP32-S3 dưới dạng ngắt cạnh xuống, cung cấp nhịp mỗi giây chính xác để kiểm tra lịch cho ăn. Module DS3231 loại phổ biến (ZS-042) có mạch nạp pin dành cho pin sạc LIR2032; khi dùng pin CR2032 không sạc được, cần loại bỏ mạch nạp này để đảm bảo an toàn cho pin.

### 2.5.3. Giao thức đồng bộ thời gian NTP

NTP (Network Time Protocol, phiên bản 4 được định nghĩa trong RFC 5905) là giao thức đồng bộ đồng hồ giữa các máy tính qua mạng, hoạt động trên UDP cổng 123. Các máy chủ thời gian được tổ chức phân tầng (stratum), tầng 0 là nguồn chuẩn như đồng hồ nguyên tử hoặc GPS. Thiết bị nhúng thường dùng SNTP – phiên bản đơn giản của NTP – để lấy thời gian UTC, sau đó quy đổi sang giờ địa phương theo múi giờ (Việt Nam: UTC+7).

Hệ thống kết hợp hai nguồn thời gian bổ sung cho nhau: khi có Internet, thời gian NTP được dùng làm chuẩn và ghi vào DS3231; khi mất Internet hoặc sau khi mất điện, thời gian được lấy từ DS3231. Nhờ vậy lịch cho ăn luôn chạy đúng giờ mà không phụ thuộc hoàn toàn vào kết nối mạng.

## 2.6. Phần tử làm lạnh nhiệt điện Peltier

### 2.6.1. Hiệu ứng Peltier

Hiệu ứng Peltier do nhà vật lý Jean Charles Athanase Peltier phát hiện năm 1834: khi cho dòng điện một chiều chạy qua mối nối giữa hai vật liệu dẫn điện khác nhau, nhiệt lượng sẽ bị hấp thụ tại một mối nối và tỏa ra tại mối nối còn lại. Phần tử làm lạnh nhiệt điện (TEC – Thermoelectric Cooler, thường gọi là “sò nóng lạnh”) gồm nhiều cặp bán dẫn loại N và loại P (thường là bismuth telluride) mắc nối tiếp về điện và song song về nhiệt, kẹp giữa hai tấm gốm. Khi cấp điện, một mặt trở nên lạnh và mặt kia nóng lên; đảo chiều dòng điện thì đảo chiều truyền nhiệt.

Ưu điểm của TEC là không có bộ phận chuyển động, không dùng môi chất lạnh, kích thước nhỏ, dễ điều khiển bằng điện. Nhược điểm là hiệu suất (hệ số COP) thấp: mặt nóng phải thải ra môi trường cả nhiệt lượng hút từ mặt lạnh lẫn toàn bộ công suất điện tiêu thụ, vì vậy tản nhiệt mặt nóng quyết định hiệu quả làm lạnh. Nếu mặt nóng không được giải nhiệt tốt, nhiệt sẽ truyền ngược về mặt lạnh và TEC có thể bị hỏng do quá nhiệt.

### 2.6.2. Sò TEC1-12706 và hệ làm mát nước

Bảng 2.4. Thông số điển hình TEC1-12706

Thông số | Giá trị điển hình
Số cặp bán dẫn | 127
Điện áp định mức / cực đại | 12 V / khoảng 15,4 V
Dòng điện cực đại | Khoảng 6,4 A
Công suất hút nhiệt cực đại (Qmax) | Khoảng 50–60 W (tùy nhà sản xuất)
Chênh lệch nhiệt độ cực đại (ΔTmax) | Khoảng 66–68°C (khi Qc = 0)
Kích thước | 40 × 40 × 3,8 mm

Trong hệ thống, mặt lạnh của sò được ép vào khối nhôm tản nhiệt nước (water block) 40 × 40 mm bằng keo tản nhiệt; bơm đẩy nước từ bể qua water block rồi trở về bể, nhiệt của nước được truyền sang mặt lạnh. Mặt nóng được gắn bộ tản nhiệt nhôm và quạt 12 V. Vì sò tiêu thụ dòng lên đến khoảng 6 A ở 12 V, nguồn cấp và dây dẫn phải được tính toán với biên độ dự phòng.

## 2.7. Linh kiện đóng ngắt tải: relay và MOSFET

### 2.7.1. Relay điện từ

Relay điện từ gồm cuộn dây và bộ tiếp điểm cơ khí (COM, NO – thường mở, NC – thường đóng). Khi có dòng qua cuộn dây, lực từ hút lá tiếp điểm chuyển từ NC sang NO. Relay cách ly hoàn toàn giữa mạch điều khiển và mạch công suất, chịu được dòng lớn (loại SRD-05VDC-SL-C: 10 A ở 30 VDC) nhưng có tuổi thọ cơ khí giới hạn, tốc độ chậm và cần diode dập xung khi ngắt cuộn dây. Vì vậy phần mềm cần tránh đóng ngắt relay liên tục – trong đề tài, sò lạnh phải nghỉ tối thiểu 60 s giữa hai lần bật.

Module relay phổ biến dùng opto PC817 để cách ly và kích ở mức thấp (Active-LOW). Khi chân VCC của module là 5 V trong khi GPIO của ESP32-S3 chỉ đạt 3,3 V ở mức cao, chênh lệch 1,7 V vẫn có thể làm LED trong opto dẫn yếu khiến relay không ngắt hoàn toàn. Giải pháp là tách nguồn: chân VCC (phía opto) nối 3,3 V và chân JD-VCC (cuộn relay) nối 5 V.

### 2.7.2. MOSFET kênh N mức logic

MOSFET kênh N hoạt động như một khóa điện tử điều khiển bằng điện áp cổng–nguồn VGS, có tốc độ đóng ngắt cao, không hao mòn cơ khí và cho phép điều khiển PWM. IRLZ44N là MOSFET “logic-level” có điện áp ngưỡng VGS(th) khoảng 1–2 V, điện áp VDS tối đa 55 V và điện trở dẫn RDS(on) cỡ vài chục mΩ, phù hợp để ESP32-S3 điều khiển trực tiếp các tải nhỏ như quạt 12 V. Khi tải có tính cảm (quạt, bơm), cần mắc diode ngược song song với tải để bảo vệ MOSFET khỏi điện áp cảm ứng khi ngắt.

## 2.8. Động cơ servo MG90S và điều chế độ rộng xung PWM

Động cơ servo gồm động cơ DC, hộp số, biến trở phản hồi vị trí và mạch điều khiển vòng kín. Góc quay được điều khiển bằng tín hiệu PWM chu kỳ 20 ms (50 Hz), trong đó độ rộng xung mức cao khoảng 0,5–2,4 ms tương ứng góc 0°–180°. MG90S là micro servo bánh răng kim loại, hoạt động ở 4,8–6 V với mô-men giữ khoảng 1,8–2,2 kg·cm, bền hơn loại bánh răng nhựa SG90 khi phải xoay hộc thức ăn nhiều lần mỗi ngày.

Khi khởi động hoặc bị kẹt, servo có thể tiêu thụ dòng đỉnh hàng trăm mA, kéo sụt nguồn 5 V và gây reset vi điều khiển (lỗi BROWNOUT_RST). Các biện pháp khắc phục gồm: cấp nguồn servo từ mạch buck riêng thay vì cổng USB, đặt tụ điện dung lớn (1000 µF) sát servo, quay góc từ từ theo từng bước nhỏ và ngắt xung PWM (detach) khi không sử dụng.

## 2.9. Mạch nguồn hạ áp Buck LM2596

Mạch buck là bộ chuyển đổi DC–DC hạ áp dạng xung: khóa bán dẫn đóng ngắt với tần số cao, năng lượng được tích trữ và giải phóng qua cuộn cảm, tụ điện lọc phẳng điện áp ra. Ở chế độ lý tưởng, điện áp ra bằng tích của điện áp vào và chu kỳ nhiệm vụ D (Vout = D·Vin). So với bộ ổn áp tuyến tính, mạch buck có hiệu suất cao hơn nhiều khi chênh lệch điện áp vào–ra lớn (12 V xuống 5 V), nên ít tỏa nhiệt.

LM2596 là IC ổn áp buck của Texas Instruments với dòng ra danh định 3 A, tần số đóng ngắt cố định 150 kHz và điện áp vào tối đa 40 V. Trên thực tế, module LM2596 giá rẻ không có tản nhiệt chỉ nên hoạt động liên tục ở khoảng 2 A; điện áp ra được chỉnh bằng biến trở và phải được đo, chỉnh về 5,0 V trước khi nối tải.

## 2.10. Giao thức truyền thông MQTT

MQTT (Message Queuing Telemetry Transport) là giao thức truyền thông điệp nhẹ theo mô hình xuất bản/đăng ký (publish/subscribe), được thiết kế cho thiết bị tài nguyên hạn chế và mạng băng thông thấp; phiên bản 3.1.1 và 5.0 là chuẩn của tổ chức OASIS. Kiến trúc MQTT gồm máy chủ trung gian (broker) và các client. Client xuất bản thông điệp lên một chủ đề (topic) – chuỗi phân cấp bằng dấu “/”, ví dụ hcmute/esd/beca-nhomXX/telemetry – và broker chuyển thông điệp đến mọi client đã đăng ký topic đó. Nhờ vậy thiết bị và giao diện web không cần biết địa chỉ của nhau.

Bảng 2.5. Các đặc tính MQTT được sử dụng trong đề tài

Đặc tính | Ý nghĩa | Ứng dụng trong hệ thống
QoS 0 / 1 / 2 | Tối đa một lần / ít nhất một lần / đúng một lần | Telemetry dùng QoS 0; trạng thái online dùng QoS 1
Retained message | Broker lưu thông điệp cuối cùng của topic cho client mới | Web vừa mở biết ngay thiết bị online/offline
Last Will and Testament | Broker tự phát thông điệp khi client mất kết nối bất thường | Tự báo “offline” khi ESP32 mất điện/mất mạng
Keep-alive | Gói ping định kỳ để phát hiện mất kết nối | Phát hiện và tự kết nối lại
Cổng kết nối | TCP 1883, TLS 8883, WebSocket | ESP32 dùng TCP 1883; trình duyệt dùng WebSocket bảo mật 8884

Dữ liệu trong thông điệp được mã hóa theo định dạng JSON để dễ đọc, dễ mở rộng và được hỗ trợ trực tiếp bởi JavaScript ở phía web cũng như thư viện ArduinoJson ở phía vi điều khiển.

## 2.11. Điều khiển ON/OFF có vùng trễ (Hysteresis)

Điều khiển ON/OFF là phương pháp đơn giản nhất: cơ cấu chấp hành chỉ có hai trạng thái bật hoặc tắt. Nếu chỉ dùng một ngưỡng duy nhất, khi nhiệt độ dao động nhỏ quanh ngưỡng (do nhiễu đo hoặc quán tính nhiệt) cơ cấu chấp hành sẽ bật/tắt liên tục, gây hao mòn relay và dao động nhiệt độ. Điều khiển có vùng trễ khắc phục điều này bằng hai ngưỡng tách biệt:

Nếu T ≥ T_ON (27,0°C) → BẬT làm mát

Nếu T ≤ T_OFF (25,5°C) → TẮT làm mát

Nếu T_OFF < T < T_ON → GIỮ NGUYÊN trạng thái trước đó

Độ rộng vùng trễ ΔH = T_ON − T_OFF = 1,5°C là sự cân bằng giữa độ ổn định nhiệt độ (vùng trễ hẹp) và số lần đóng ngắt (vùng trễ rộng). Bổ sung thời gian nghỉ tối thiểu giữa hai lần bật và cho quạt tản nhiệt chạy thêm sau khi tắt sò giúp bảo vệ relay và sò Peltier. Với hệ có quán tính nhiệt lớn và công suất làm lạnh không điều chỉnh liên tục như bể cá dùng sò Peltier qua relay, phương pháp này đơn giản, tin cậy và đủ đáp ứng yêu cầu.

## 2.12. Máy trạng thái và lập trình không chặn (non-blocking)

Trong vi điều khiển chạy không có hệ điều hành thời gian thực ở tầng ứng dụng, mọi tác vụ chia sẻ một vòng lặp chính. Việc dùng hàm trễ delay() làm vòng lặp bị chặn: trong thời gian đó hệ thống không đọc được lệnh MQTT, không cập nhật màn hình và có thể mất kết nối. Giải pháp là mô hình hóa các tác vụ kéo dài (quay servo, phát còi, đọc cảm biến) thành máy trạng thái hữu hạn (FSM): mỗi lần vòng lặp chạy, tác vụ chỉ kiểm tra thời gian đã trôi qua bằng millis() và chuyển trạng thái khi đủ điều kiện, sau đó trả quyền điều khiển ngay. Kết hợp với ngắt phần cứng (xung 1 Hz từ DS3231) và cờ báo sự kiện, firmware đáp ứng nhanh và dễ mở rộng.

## 2.13. Yêu cầu về nhiệt độ nước trong nuôi cá cảnh

Cá là động vật biến nhiệt, thân nhiệt và tốc độ trao đổi chất phụ thuộc trực tiếp vào nhiệt độ nước. Nhiệt độ tăng làm giảm độ hòa tan oxy trong nước đồng thời làm tăng nhu cầu oxy của cá, dẫn đến thiếu oxy khi nước quá nóng. Phần lớn cá cảnh nhiệt đới nuôi phổ biến thích hợp với nước khoảng 24–28°C; sự thay đổi nhiệt độ lớn trong thời gian ngắn gây stress và sốc nhiệt. Do đó, bên cạnh việc giữ nhiệt độ trong dải mục tiêu, hệ thống cần tránh làm lạnh quá mức và cảnh báo khi nhiệt độ vượt ngưỡng an toàn (trong đề tài chọn 22°C và 30°C).

## 2.14. Kết luận chương

Chương 2 đã trình bày cơ sở lý thuyết về quy trình thiết kế hệ thống nhúng, vi điều khiển ESP32-S3, các cảm biến và chuẩn giao tiếp 1-Wire, I2C, đồng hồ thời gian thực DS3231 cùng giao thức NTP, nguyên lý làm lạnh Peltier, các linh kiện đóng ngắt tải, servo, mạch nguồn buck, giao thức MQTT, thuật toán điều khiển có trễ và kỹ thuật lập trình không chặn. Đây là nền tảng để lựa chọn linh kiện, thiết kế kiến trúc phần cứng – phần mềm và đặc tả chi tiết hệ thống trong Chương 3.

BỐ CỤC DỰ KIẾN CÁC CHƯƠNG TIẾP THEO

- Chương 3 – Thiết kế hệ thống: 3.1 Đặc tả yêu cầu (FR/NFR, phương pháp kiểm chứng) · 3.2 Kiến trúc tổng thể · 3.3 Thiết kế phần cứng (lựa chọn linh kiện, sơ đồ nguyên lý, sơ đồ chân Rev2, ngân sách công suất) · 3.4 Thiết kế phần mềm (phân lớp, máy trạng thái, giao thức MQTT, giao diện web).
- Chương 4 – Kết quả và kiểm thử: kết quả kiểm tra module, tích hợp, bảng test case theo yêu cầu, đo đạc năng lực làm lạnh, đánh giá.
- Chương 5 – Kết luận và hướng phát triển.

TÀI LIỆU THAM KHẢO

[1] Huỳnh Hoàng Hà, Bài giảng Thiết kế hệ thống nhúng (Embedded System Design), Trường Đại học Sư phạm Kỹ thuật TP.HCM.

[2] Espressif Systems, ESP32-S3 Series Datasheet.

[3] Espressif Systems, ESP32-S3-DevKitC-1 User Guide.

[4] Maxim Integrated (Analog Devices), DS18B20 Programmable Resolution 1-Wire Digital Thermometer – Datasheet.

[5] Maxim Integrated (Analog Devices), DS3231 Extremely Accurate I2C-Integrated RTC/TCXO/Crystal – Datasheet.

[6] NXP Semiconductors, UM10204 – I2C-bus Specification and User Manual.

[7] Sino Wealth, SH1106 132 × 64 Dot Matrix OLED/PLED Segment/Common Driver with Controller – Datasheet.

[8] Texas Instruments, LM2596 SIMPLE SWITCHER Power Converter 150-kHz 3-A Step-Down Voltage Regulator – Datasheet.

[9] Infineon (International Rectifier), IRLZ44N HEXFET Power MOSFET – Datasheet.

[10] Hebei I.T. (Shanghai) Co., Ltd., TEC1-12706 Thermoelectric Cooler – Specification.

[11] OASIS, MQTT Version 3.1.1, OASIS Standard, 2014.

[12] D. Mills, J. Martin, J. Burbank, W. Kasch, RFC 5905 – Network Time Protocol Version 4: Protocol and Algorithms Specification, IETF, 2010.

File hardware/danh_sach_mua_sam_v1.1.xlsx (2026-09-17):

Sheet: Hướng Dẫn & Mục Lục
BẢNG DỰ TOÁN & DANH SÁCH MUA SẮM LINH KIỆN
Dự án: Bể cá thông minh tích hợp IoT + AI (ESP32-S3 & Raspberry Pi W)
HƯỚNG DẪN SỬ DỤNG FILE
1. File này gồm 2 Tab: 'Hướng Dẫn & Mục Lục' (tab này) và 'Danh Sách Mua Sắm' (chứa bảng giá và link chi tiết).
2. Cột 'Trạng thái' trong tab mua sắm có bộ lọc Dropdown: 'Chưa mua', 'Đang giao', 'Đã mua' để bạn dễ quản lý.
3. Các cột màu xanh nhạt (Đơn giá, Số lượng, Trạng thái) là các ô bạn có thể nhập/thay đổi thủ công.
4. Cột 'Thành tiền' được tính tự động bằng công thức Excel, không cần nhập tay.
5. File đã được cấu hình sẵn để in (Print-ready) ở dạng Landscape khổ A4.
CHÚ GIẢI MÀU SẮC
Màu sắc | Ý nghĩa | Ví dụ sử dụng
Xanh nhạt | Ô dữ liệu nhập tay (Input) | Số lượng, Đơn giá
Lá cây nhạt | Ô tính toán tự động (Formula) | Thành tiền, Tổng cộng
Không màu | Thông tin tham khảo cố định | Tên linh kiện, Mô tả
👉 Chuyển sang Tab danh sách mua sắm: | Danh Sách Mua Sắm

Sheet: Danh Sách Mua Sắm
DANH SÁCH CHI TIẾT VÀ DỰ TOÁN LINH KIỆN HỒ CÁ THÔNG MINH
Cập nhật ngày: 2026-09-17 | Phiên bản v1.1 (Rev2 phần cứng + RTC) – giá mục mới là ước tính, cần kiểm tra lại
Danh mục | Tên linh kiện / Thiết bị | Thông số kỹ thuật / Vai trò | Số lượng | Đơn giá (VND) | Thành tiền (VND) | Cửa hàng gợi ý | Link tham khảo | Trạng thái | Thay đổi v1.1
Mạch & Cảm biến | ESP32-S3 DevKit C (N8R8/N16R8) | Vi điều khiển trung tâm IoT + AI, 8MB PSRAM xử lý ảnh/wifi mạnh mẽ | 1 | 180000 | 180000 | Hshop.vn | Link sản phẩm (https://hshop.vn/collections/all) | Chưa mua
Mạch & Cảm biến | Màn hình OLED 1.3 Inch I2C (SH1106) | 128x64px, I2C 0x3C, cấp 3.3V – dùng chung bus I2C với RTC DS3231 | 1 | 110000 | 110000 | Hshop.vn | Link sản phẩm (https://hshop.vn/products/man-hinh-lcd-tft-1-54-inch-st7789-spi-interface) | Chưa mua | THAY TFT ST7789 SPI → OLED I2C cho khớp firmware & bus chung RTC
Mạch & Cảm biến | Cảm biến nhiệt độ DS18B20 chống nước | Đọc nhiệt độ nước hồ cá, dây dài bọc kim loại chống nước tốt | 1 | 35000 | 35000 | Hshop.vn | Link sản phẩm (https://hshop.vn/collections/all) | Chưa mua
Mạch & Cảm biến | Micro Servo MG90S nhông kim loại | Truyền động hộc xoay thức ăn tự động bền bỉ, lực kéo khỏe hơn SG90 | 1 | 45000 | 45000 | Hshop.vn | Link sản phẩm (https://hshop.vn/collections/all) | Chưa mua
Mạch & Cảm biến | Module RTC DS3231 + Pin CR2032 | DS3231 ±2ppm, I2C 0x68, SQW 1Hz → GPIO7. Cấp 3.3V; gỡ trở/diode sạc nếu dùng CR2032 | 1 | 30000 | 30000 | Hshop.vn | Link sản phẩm (https://hshop.vn/collections/all) | Chưa mua | Tích hợp ở W6 (Rel)
Hệ Chiller | Bộ Tản Nhiệt Cho Sò Nóng Lạnh Đôi | Bộ đầy đủ gồm tản nhôm, quạt 12V thổi mát mặt nóng sò Peltier | 1 | 178000 | 178000 | Điện tử Tuyết Nga | Link sản phẩm (https://dientutuyetnga.com/products/bo-tan-nhiet-cho-so-nong-lanh-doi-ban-day-du) | Chưa mua
Hệ Chiller | Sò nóng lạnh Peltier TEC1-12706 12V 60W | Sò nóng lạnh tạo chênh lệch nhiệt độ làm lạnh nước bể cá | 1 | 60000 | 60000 | Caka.vn / Tuyết Nga | Link sản phẩm (https://caka.vn/so-nong-lanh-12v-tec1-12706-60w-12710-100w-12715-150w) | Chưa mua
Hệ Chiller | Khối nhôm tản nhiệt nước (Water Block) 40x40mm | Khối nhôm dẫn nước từ lọc thác chạy qua mặt lạnh của sò | 1 | 45000 | 45000 | Caka.vn | Link sản phẩm (https://caka.vn/collections/all) | Chưa mua
Hệ Chiller | Keo tản nhiệt MX-4 & Ống dẻo silicone | Tăng tiếp xúc truyền nhiệt mặt sò, ống dẫn nước tuần hoàn | 1 | 40000 | 40000 | Caka.vn / Tuyết Nga | Link sản phẩm (https://caka.vn/collections/all) | Chưa mua
Nguồn & Phụ trợ | Nguồn tổ ong 12V - 10A (120W) | Tổng dòng đỉnh ≈ 8.2A (sò 6.4A + bơm + quạt + nhánh 5V) | 1 | 180000 | 180000 | Điện tử Tuyết Nga | Link sản phẩm (https://dientutuyetnga.com/collections/nguon-to-ong-nguon-xung) | Chưa mua | NÂNG 5A → 10A (5A không đủ cho sò TEC1-12706)
Nguồn & Phụ trợ | Mạch hạ áp Buck LM2596 | Hạ áp từ 12V xuống 5V/3A cấp cho ESP32, Servo, Màn hình | 1 | 20000 | 20000 | Điện tử Tuyết Nga | Link sản phẩm (https://dientutuyetnga.com/collections/mach-giam-ap) | Chưa mua
Nguồn & Phụ trợ | Linh kiện PCB phụ trợ | Mosfet IRLZ44N (quạt), Buzzer 5V, trở 4.7k/10k/1k/100Ω, nút nhấn, dây bẹ | 1 | 90000 | 90000 | Tuyệt Nga / Caka / ICdayroi | Link sản phẩm (https://dientutuyetnga.com/collections/all) | Chưa mua | IRLZ44N dùng điều khiển quạt riêng (GPIO15)
Nguồn & Phụ trợ | Mạch PCB Đục Lỗ 1 Mặt Màu Xanh FR4 7x9cm | Phíp thủy tinh cao cấp cứng cáp, chịu nhiệt tốt để tự hàn thủ công | 1 | 15000 | 15000 | Caka.vn | Link sản phẩm (https://caka.vn/mach-pcb-duc-lo-1-mat-mau-xanh-loai-tot-de-han) | Chưa mua
Mạch & Cảm biến | Module Relay 2 kênh 5V (opto, có jumper JD-VCC) | Đóng ngắt sò Peltier (CH1) & bơm (CH2), 10A/30VDC | 1 | 25000 | 25000 | Hshop.vn / Tuyết Nga | Link sản phẩm (https://caka.vn/mach-pcb-duc-lo-1-mat-mau-xanh-loai-tot-de-han) | Chưa mua | BỔ SUNG – thiếu trong v1.0
Hệ Chiller | Máy bơm mini 12V (bơm màng 385 / bơm chìm) | Tuần hoàn nước bể → water block → bể | 1 | 70000 | 70000 | Caka.vn / Tuyết Nga | Link sản phẩm (https://caka.vn/mach-pcb-duc-lo-1-mat-mau-xanh-loai-tot-de-han) | Chưa mua | BỔ SUNG – thiếu trong v1.0
Nguồn & Phụ trợ | Cầu chì 10A + đế cầu chì | Bảo vệ quá dòng đầu vào 12V | 1 | 15000 | 15000 | Tuyết Nga | Link sản phẩm (https://caka.vn/mach-pcb-duc-lo-1-mat-mau-xanh-loai-tot-de-han) | Chưa mua | BỔ SUNG – an toàn điện
Nguồn & Phụ trợ | Linh kiện driver & lọc nguồn | S8050 (còi), 1N5819 x2, tụ 1000µF/16V, 470µF x2, 100nF x5 | 1 | 25000 | 25000 | ICdayroi / Tuyết Nga | Link sản phẩm (https://caka.vn/mach-pcb-duc-lo-1-mat-mau-xanh-loai-tot-de-han) | Chưa mua | BỔ SUNG – còi qua transistor, chống ngược, tụ servo
Nguồn & Phụ trợ | Connector & header | Domino KF301 2P x6, header cái 2x22, JST-XH 4P x3 | 1 | 35000 | 35000 | Caka.vn | Link sản phẩm (https://caka.vn/mach-pcb-duc-lo-1-mat-mau-xanh-loai-tot-de-han) | Chưa mua | BỔ SUNG – mạch tháo lắp được
Nguồn & Phụ trợ | Dây điện 1mm² đỏ/đen (1m mỗi màu) | Đường lực 12V cho sò Peltier | 1 | 20000 | 20000 | Tuyết Nga | Link sản phẩm (https://caka.vn/mach-pcb-duc-lo-1-mat-mau-xanh-loai-tot-de-han) | Chưa mua | BỔ SUNG – không đi dòng 6A trên PCB lỗ
Máy tính nhúng (Tùy chọn) | Máy tính Raspberry Pi Zero 2 W | Làm server trung gian điều khiển, chạy local AI nhận diện hoặc Home Assistant | 1 | 729000 | 729000 | Hshop.vn | Link sản phẩm (https://hshop.vn/products/may-tinh-raspberry-pi-zero-2-w) | Chưa mua | Tùy chọn – không bắt buộc cho W6
TỔNG CỘNG |  |  |  |  | 1218000 | (chưa gồm Raspberry Pi tùy chọn)
 |  |  |  | Kể cả RPi: | 1947000

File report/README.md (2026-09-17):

# Report

- `Report_Chuong1_2.docx` – Chương 1: Tổng quan đề tài · Chương 2: Cơ sở lý thuyết (kèm mục lục dự kiến Chương 3–5).
- Chương 3–5 hoàn thiện ở W8 (xem `docs/03`).

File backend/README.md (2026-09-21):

# Backend (Render)

Nghe MQTT 24/7, ghi Postgres (Neon), phục vụ REST API và trợ lý dữ liệu cho dashboard.

## Chạy trên máy
```bash
cd backend
npm install
set DATABASE_URL=postgresql://...        # Windows PowerShell: $env:DATABASE_URL="postgresql://..."
node server.js                           # http://localhost:8000/api/health
```

## Biến môi trường
| Biến | Mặc định | Ý nghĩa |
|---|---|---|
| `DATABASE_URL` | – | Chuỗi kết nối Neon (bắt buộc) |
| `MQTT_URL` | `mqtt://broker.hivemq.com:1883` | Broker cho backend |
| `MQTT_WS_URL` | `wss://broker.hivemq.com:8884/mqtt` | Broker WebSocket trả cho web qua `/api/config` |
| `MQTT_TOPIC_BASE` | `smartaquarium_node2026` | Trùng firmware + `index.html` |
| `MQTT_USER` / `MQTT_PASS` | – | Khi dùng HiveMQ Cloud |
| `API_KEY` | rỗng | Bắt buộc header `X-API-Key` cho POST/PUT |
| `INGEST_MIN_INTERVAL_MS` | 10000 | Gộp telemetry, tránh phình database |
| `RETENTION_DAYS` | 60 | Tự xóa dữ liệu cũ |

## Endpoint
`/api/health` · `/api/config` · `/api/status` · `/api/history?hours=` · `/api/stats?hours=` · `/api/feeds?days=`
· `/api/energy/daily?days=` · `/api/events` · `/api/commands` · `/api/availability`
· `POST /api/command` · `GET|PUT /api/settings` · `GET /api/export/{telemetry|events|commands|availability}.csv`
· `POST /api/chat`

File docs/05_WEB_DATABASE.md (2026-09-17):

# 05 – WEB ↔ DATABASE ↔ ESP32 TRÊN VERCEL + HIVEMQ

> Firmware **v2.2.0** · Dashboard **v4** · Backend **Vercel Functions** · Database **Postgres (Neon, tạo trong Vercel)** · MQTT **HiveMQ** (public hoặc Cloud)
> Chỉ dùng **2 tài khoản**: Vercel (kèm Neon qua Marketplace) và HiveMQ. Không cần server riêng, không cần chạy SQL tay.

---

## 1. Kiến trúc

```mermaid
flowchart LR
  subgraph ESP["ESP32-S3"]
    LOOP["loop() core 1<br/>điều khiển · OLED · MQTT"]
    Q["Queue 40 bản ghi"]
    TASK["dbTask core 0<br/>gom lô ≤ 20 → HTTPS"]
    LOOP --> Q --> TASK
  end
  HMQ["HiveMQ<br/>(public hoặc Cloud)"]
  subgraph VERCEL["Vercel (1 project, 1 repo GitHub)"]
    WEB["index.html"]
    API["/api/* Functions"]
    PG[("Postgres Neon")]
    CRON["Cron 3h sáng<br/>dọn dữ liệu cũ"]
    API --> PG
    CRON --> API
  end
  LOOP <-->|"MQTT 1883 / TLS 8883"| HMQ
  WEB <-->|"WSS 8884: lệnh, ACK, realtime"| HMQ
  TASK -->|"POST /api/ingest + x-device-key"| API
  WEB -->|"GET /api/stats, history, feeds, events, export"| API
  WEB -->|"GET /api/config (topic, tài khoản MQTT web)"| API
```

| Đường | Dùng cho | Tần suất |
|---|---|---|
| **HiveMQ (MQTT)** | Bấm nút, ACK, trạng thái realtime, biểu đồ *Live* | 2 s |
| **Vercel API → Postgres** | Biểu đồ 1h/6h/24h/7 ngày, KPI, cho ăn theo ngày, nhật ký, CSV | 1 bản ghi/phút + sự kiện |

### Luồng bấm nút (có xác nhận)
```mermaid
sequenceDiagram
  participant W as Web
  participant H as HiveMQ
  participant E as ESP32
  participant A as Vercel API
  W->>W: khóa nút, spinner, tạo id
  W->>H: …/command {"device":"feed","id":"k3x9"}
  H->>E: lệnh
  E->>H: …/ack {"id":"k3x9","ok":true,"msg":"Dang cho ca an"}
  H->>W: ack → mở nút, toast ✅/❌ (6 s không có → timeout)
  E-->>A: POST /api/ingest (events: command, feed)
```

---

## 2. Cấu trúc code backend

```text
api/
├── ingest.js        POST  ESP32 ghi dữ liệu theo lô (header x-device-key)
├── history.js       GET   ?hours=  → điểm gom 1 phút / 10 phút / 1 giờ
├── stats.js         GET   ?hours=  → TB/min/max, % sò chạy, số lần ăn, cảnh báo
├── feeds.js         GET   ?days=   → số lần ăn/ngày (theo lịch / thủ công), giờ VN
├── events.js        GET   ?type=&limit=
├── export.js        GET   ?hours=  → file CSV
├── config.js        GET   cấu hình MQTT cho web (lấy từ Environment Variables)
├── health.js        GET   kiểm tra env + database
└── cron/cleanup.js  GET   Vercel Cron xóa dữ liệu cũ (cần CRON_SECRET)
lib/  db.js (pool pg + tự tạo bảng) · http.js · schema.js
db/   schema.sql (tham khảo – API tự chạy, không cần chạy tay)
```

**Bảo mật:** chỉ ai có `DEVICE_KEY` mới ghi được; tên cột được whitelist, giá trị kiểm tra kiểu/phạm vi, SQL dùng tham số `$1…` (chống SQL injection); thời gian lệch > 3 ngày bị thay bằng giờ server.

> **Đã kiểm thử** trên PostgreSQL 16 + giả lập Vercel: ghi sai/thiếu khóa → 401; body sai → 400; bản ghi rác bị loại (`rejected`); 865 bản ghi qua 15 lô; stats/history/feeds/events/export/cron/config trả đúng; web v4 chạy trong Chromium: KPI, biểu đồ 24h, nhật ký, lọc, CSV, ACK nút – không lỗi JS.

---

## 3. Triển khai từng bước

> ### ⚡ Cấu hình nhóm đang dùng: KHÔNG MẬT KHẨU (mặc định trong code)
> - Web mở trực tiếp `https://<app>.vercel.app`, không cần đăng nhập.
> - HiveMQ **public** (`broker.hivemq.com`), không user/pass.
> - API không cần `DEVICE_KEY`, không cần `CRON_SECRET`.
> - Firmware đã điền sẵn Wi-Fi `HO TRO SINH VIEN`.
>
> **Chỉ cần làm:** Bước 1 (push GitHub) → Bước 2 (Storage → Neon → Connect Project → Redeploy) → trong firmware sửa **`API_BASE_URL`** thành domain Vercel của nhóm → nạp code → mở `/api/health`.
> **Bỏ qua** Bước 3B và mọi biến ở Bước 4 trừ `DATABASE_URL` (Vercel tự thêm).
> Muốn bật bảo mật lại sau này: chỉ cần thêm biến `DEVICE_KEY` trên Vercel và điền cùng giá trị vào firmware.

### Bước 1 – Đưa code lên GitHub
Giải nén repo → trong thư mục `smart-aquarium-ai`:
```bash
git add .
git commit -m "W6: Vercel API + Postgres + HiveMQ, FW 2.2.0, dashboard v4"
git push
```
Vercel (đã nối repo từ trước) sẽ tự deploy. Thư mục `api/` được Vercel nhận thành Functions, `package.json` cài `pg` tự động.

### Bước 2 – Tạo database Postgres trong Vercel
1. Vercel → mở project → tab **Storage** → **Create Database** → chọn **Neon** (Postgres).
2. Region: **Singapore (ap-southeast-1)** → Create → **Connect Project** → tick Production/Preview/Development.
3. Vercel tự thêm biến `DATABASE_URL` (và `POSTGRES_URL`…) vào **Settings → Environment Variables**.
4. **Không cần chạy SQL**: lần gọi API đầu tiên sẽ tự tạo bảng `telemetry`, `events`.

### Bước 3 – Chọn HiveMQ

**(A) HiveMQ public** – nhanh, không cần tài khoản, ai biết topic cũng điều khiển được → **bắt buộc** đặt topic khó đoán.

**(B) HiveMQ Cloud (khuyên dùng khi demo)** – có mật khẩu:
1. https://console.hivemq.cloud → tạo cluster **Serverless (Free)**.
2. Tab **Overview**: ghi lại **Cluster URL** (`xxxxxxxx.s1.eu.hivemq.cloud`), port **8883** (TLS) và **8884** (WebSocket TLS).
3. Tab **Access Management** → tạo **2 tài khoản**:
   - `esp32` / mật khẩu mạnh – quyền **Publish and Subscribe** (dùng trong firmware).
   - `web` / mật khẩu khác – quyền **Publish and Subscribe** (dùng trên web; mật khẩu này trình duyệt nhìn thấy được, nên tách riêng để đổi khi cần).

### Bước 4 – Environment Variables trên Vercel
**Settings → Environment Variables** (Production), sau đó **Deployments → Redeploy**:

| Biến | Giá trị | Bắt buộc |
|---|---|---|
| `DATABASE_URL` | Vercel tự thêm ở Bước 2 | ✅ |
| `DEVICE_KEY` | chuỗi bí mật ≥ 16 ký tự, vd `aq-nhom05-7Hk2pQ9x` | ✅ |
| `CRON_SECRET` | chuỗi ngẫu nhiên bất kỳ (Vercel gửi kèm khi chạy cron) | ✅ |
| `MQTT_TOPIC_BASE` | `hcmute/esd/beca-nhom05-7hk2` (trùng firmware) | ✅ |
| `MQTT_WS_URL` | (A) `wss://broker.hivemq.com:8884/mqtt` · (B) `wss://xxxxxxxx.s1.eu.hivemq.cloud:8884/mqtt` | ✅ |
| `MQTT_WEB_USERNAME` / `MQTT_WEB_PASSWORD` | (A) để trống · (B) tài khoản `web` | (B) |
| `RETENTION_DAYS` | `30` | tùy chọn |

Kiểm tra: mở `https://<app>.vercel.app/api/health` → phải thấy `"ok": true` và các biến `true`.

### Bước 5 – Firmware
```cpp
// (A) HiveMQ public
const bool  MQTT_USE_TLS = false;
const char* MQTT_HOST    = "broker.hivemq.com";
const int   MQTT_PORT    = 1883;
const char* MQTT_USER    = "";
const char* MQTT_PASS    = "";

// (B) HiveMQ Cloud
const bool  MQTT_USE_TLS = true;
const char* MQTT_HOST    = "xxxxxxxx.s1.eu.hivemq.cloud";
const int   MQTT_PORT    = 8883;
const char* MQTT_USER    = "esp32";
const char* MQTT_PASS    = "mat-khau-esp32";

const char* TOPIC_BASE   = "hcmute/esd/beca-nhom05-7hk2";      // = MQTT_TOPIC_BASE
const char* API_BASE_URL = "https://smart-aquarium-ai.vercel.app"; // domain PRODUCTION
const char* DEVICE_KEY   = "aq-nhom05-7Hk2pQ9x";                // = DEVICE_KEY trên Vercel
```
⚠️ Dùng **domain Production** (`<tên>.vercel.app`). Link Preview (`…-git-…vercel.app`) thường bị *Deployment Protection* chặn → ESP32 nhận HTTP 401.

### Bước 6 – Kiểm tra toàn hệ thống
| # | Thao tác | Kỳ vọng |
|---|---|---|
| 1 | Serial Monitor sau khi nạp | Không có `[MQTT] Ket noi that bai`, không có `[DB] HTTP 401` |
| 2 | Mở web | 3 badge xanh: MQTT · Thiết bị online · Database OK |
| 3 | Đợi 2 phút → mở `/api/health` | `telemetry_rows` tăng |
| 4 | Bấm **CHO CÁ ĂN NGAY** | spinner → ✅ → servo chạy → nhật ký có `command` + `feed` |
| 5 | Bấm lại ngay | ❌ "Vua cho an < 60 s" |
| 6 | Rút điện ESP32, bấm **Sò lạnh** | sau 6 s ❌ "Thiết bị không phản hồi" |
| 7 | Tab **24 giờ**, **7 ngày** | biểu đồ min–max, % sò chạy, 2 đường ngưỡng |
| 8 | **Xuất CSV** | tải `aquarium_24h.csv`, mở Excel đúng tiếng Việt |
| 9 | Tắt router 5 phút rồi bật | sự kiện lúc mất mạng vẫn lên DB (≤ 40 bản ghi) |

---

## 4. Lỗi thường gặp

| Hiện tượng | Nguyên nhân / cách sửa |
|---|---|
| Serial `[MQTT] … state=4` hoặc `5` | Sai user/pass HiveMQ Cloud hoặc tài khoản thiếu quyền |
| Serial `[MQTT] … state=-2` | Sai host/port; Cloud phải `MQTT_USE_TLS=true` + port 8883 |
| Web badge `MQTT: sai tài khoản` | Sai `MQTT_WEB_USERNAME/PASSWORD` → sửa env → **Redeploy** |
| Serial `[DB] HTTP 401 Sai x-device-key` | `DEVICE_KEY` firmware ≠ Vercel, hoặc chưa Redeploy sau khi thêm biến |
| Serial `[DB] HTTP 401` trả về trang HTML | Đang dùng link Preview bị bảo vệ → dùng domain Production |
| Serial `[DB] HTTP 500 Thiếu biến môi trường DATABASE_URL` | Chưa Connect Project ở Bước 2 |
| Serial `[DB] HTTP -1` | Mất mạng/DNS, task tự thử lại |
| Web "Database: lỗi", `/api/health` báo lỗi | Xem thông báo `error` trong `/api/health` |
| Nút luôn timeout | `MQTT_TOPIC_BASE` ≠ `TOPIC_BASE` firmware, hoặc firmware cũ chưa có `/ack` |
| Mở `index.html` bằng double-click không có dữ liệu DB | Bình thường – API chỉ có trên Vercel. Muốn test local: đặt `CONFIG.API_BASE = "https://<app>.vercel.app"` |

## 5. Giới hạn gói miễn phí (kiểm tra lại trang giá khi nộp)
- **Vercel Hobby**: dành cho dự án cá nhân/phi thương mại; Cron chỉ chạy **1 lần/ngày** (đã cấu hình 20:00 UTC = 3:00 sáng VN).
- **Neon Free**: dung lượng nhỏ nhưng dư cho ~1 440 bản ghi/ngày; database tự "ngủ" khi không dùng, request đầu tiên sau đó chậm hơn vài giây.
- **HiveMQ Cloud Serverless Free**: đủ cho vài thiết bị + web của nhóm.

## 6. Mở rộng
- Cảnh báo Telegram khi `alarm`: trong `api/ingest.js`, nếu có event `alarm` → `fetch("https://api.telegram.org/bot<TOKEN>/sendMessage", …)` (lưu TOKEN trong env).
- Phân tích AI: thêm `api/insight.js` đọc `/api/history?hours=168` rồi gọi LLM tóm tắt xu hướng.
- Đăng nhập cho web: Vercel Deployment Protection (gói trả phí) hoặc tự thêm mật khẩu đơn giản ở `api/*`.

---
**Nguồn tham khảo:** [Vercel – Storage on Marketplace](https://vercel.com/docs/marketplace-storage) · [Neon – Vercel-Managed Integration](https://neon.com/docs/guides/vercel-managed-integration) · [HiveMQ Cloud Quick Start](https://docs.hivemq.com/hivemq-cloud/quick-start-guide.html) · [Vercel Cron – Usage & Pricing](https://vercel.com/docs/cron-jobs/usage-and-pricing) · [Vercel – Managing Cron Jobs](https://vercel.com/docs/cron-jobs/manage-cron-jobs)

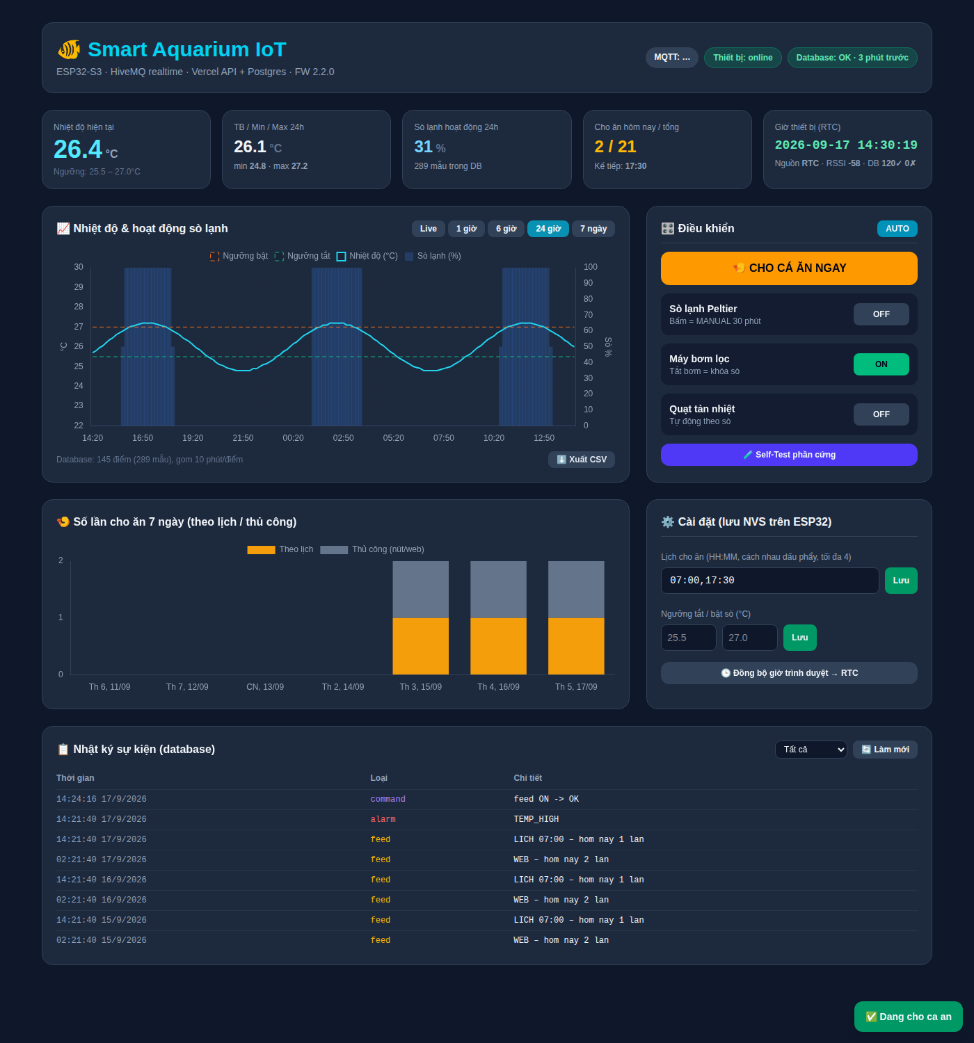
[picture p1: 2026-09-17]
docs/dashboard_v4_preview.png

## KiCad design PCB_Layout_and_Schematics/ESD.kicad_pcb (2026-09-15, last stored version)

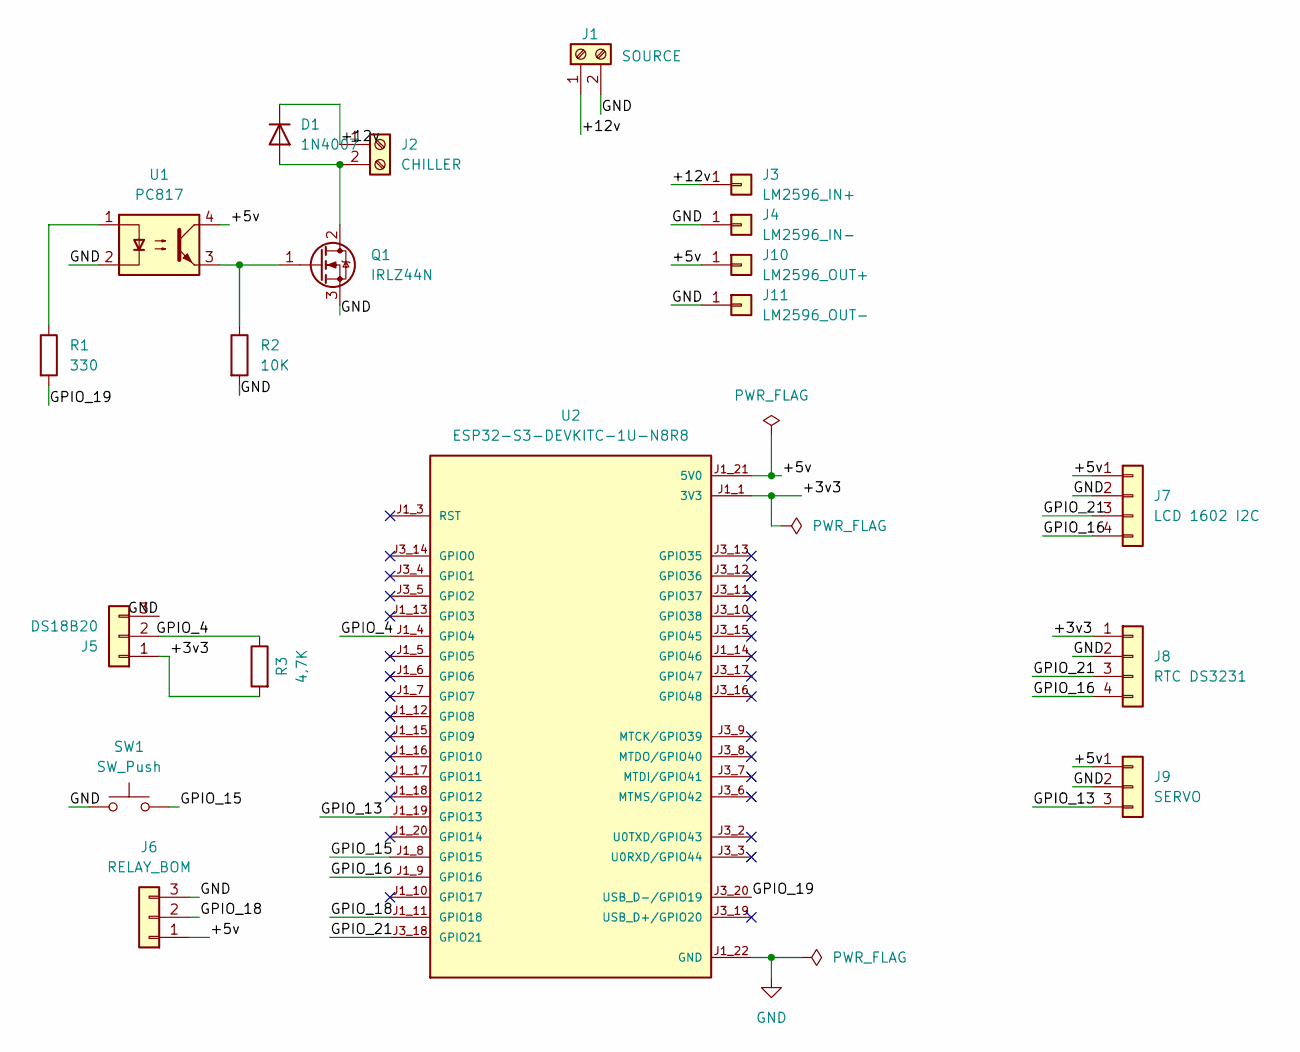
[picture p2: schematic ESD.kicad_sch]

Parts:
D1: 1N4007; D_DO-41_SOD81_P10.16mm_Horizontal
J1: SOURCE; TerminalBlock_Phoenix_MKDS-1,5-2-5.08_1x02_P5.08mm_Horizont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
J2: CHILLER; TerminalBlock_Phoenix_MKDS-1,5-2-5.08_1x02_P5.08mm_Horizont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
J3: LM2596_IN+; PinSocket_1x01_P2.54mm_Vertical
J4: LM2596_IN-; PinSocket_1x01_P2.54mm_Vertical
J5: DS18B20; PinHeader_1x03_P2.54mm_Vertical
J6: RELAY_BOM; PinHeader_1x03_P2.54mm_Vertical
J7: LCD 1602 I2C; PinHeader_1x04_P2.54mm_Vertical
J8: RTC DS3231; PinHeader_1x04_P2.54mm_Vertical
J9: SERVO; PinHeader_1x03_P2.54mm_Vertical
J10: LM2596_OUT+; PinSocket_1x01_P2.54mm_Vertical
J11: LM2596_OUT-; PinSocket_1x01_P2.54mm_Vertical
Q1: IRLZ44N; TO-220-3_Vertical
R1: 330; R_Axial_DIN0207_L6.3mm_D2.5mm_P10.16mm_Horizontal
R2: 10K; R_Axial_DIN0207_L6.3mm_D2.5mm_P10.16mm_Horizontal
R3: 4,7K; R_Axial_DIN0207_L6.3mm_D2.5mm_P10.16mm_Horizontal
SW1: SW_Push; SW_PUSH_6mm
U1: PC817; DIP-4_W7.62mm
U2: ESP32-S3-DEVKITC-1U-N8R8; MODULE_ESP32-S3-DEVKITC-1U-N8R8; PARTREV 1.1

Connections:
3V3: J5.1, J8.1, R3.2, U2.J1_1 (3V3), U2.J1_2 (3V3)
/+5v: J6.1, J7.1, J9.1, J10.1, U1.4, U2.J1_21 (5V0)
/+12v: D1.1 (K), J1.1, J2.1, J3.1
/GPIO_4: J5.2, R3.1, U2.J1_4 (GPIO4)
/GPIO_13: J9.3, U2.J1_19 (GPIO13)
/GPIO_15: SW1.2, U2.J1_8 (GPIO15)
/GPIO_16: J7.4, J8.4, U2.J1_9 (GPIO16)
/GPIO_18: J6.2, U2.J1_11 (GPIO18)
/GPIO_19: R1.2, U2.J3_20 (USB_D-/GPIO19)
/GPIO_21: J7.3, J8.3, U2.J3_18 (GPIO21)
GND: J1.2, J4.1, J5.3, J6.3, J7.2, J8.2, J9.2, J11.1, Q1.3 (S), R2.2, SW1.1, U1.2, U2.J1_22 (GND), U2.J3_1 (GND), U2.J3_21 (GND), U2.J3_22 (GND)
unnamed: D1.2 (A), J2.2, Q1.2 (D)
unnamed: Q1.1 (G), R2.1, U1.3
unnamed: R1.1, U1.1

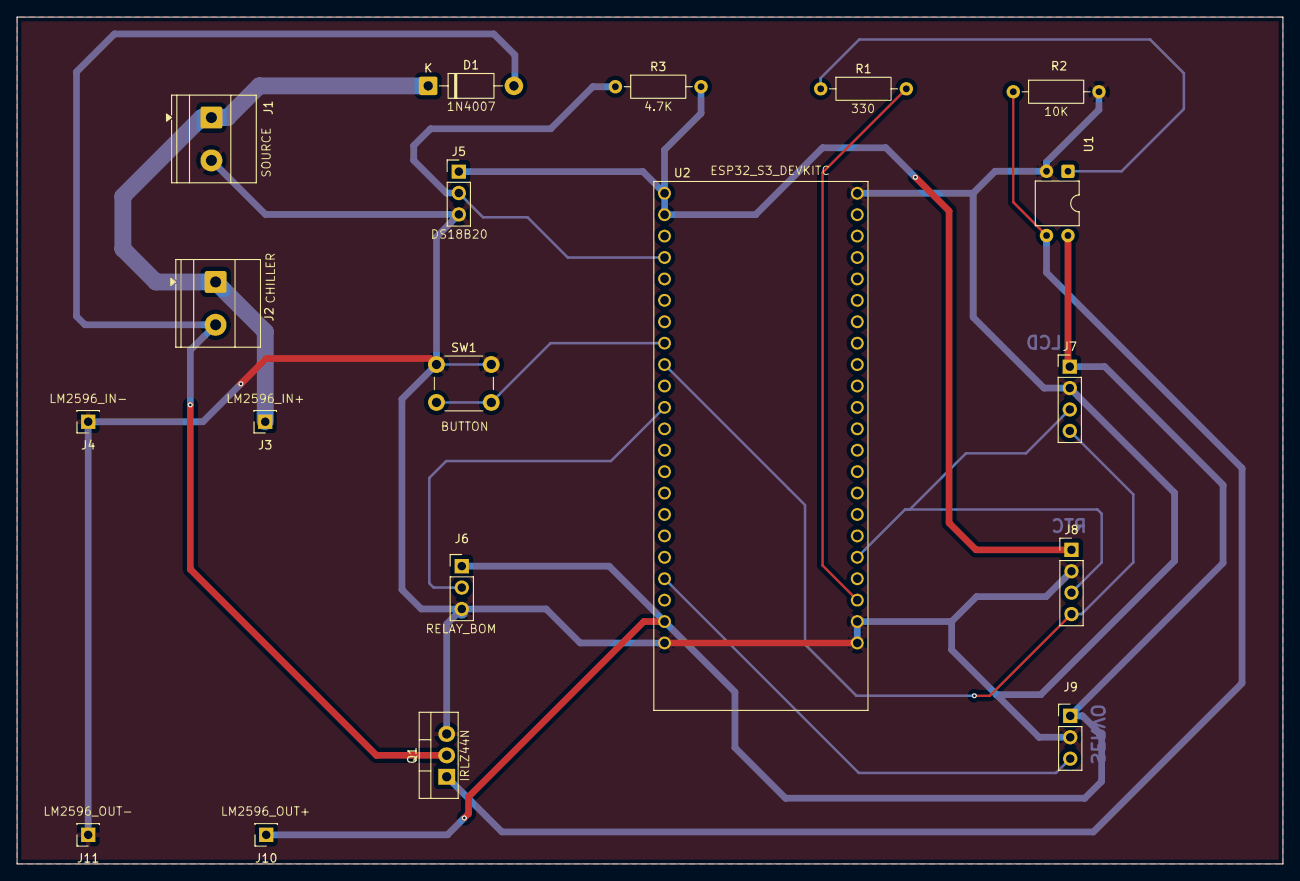
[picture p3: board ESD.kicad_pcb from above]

Board: 2 copper layers, 150.1 x 100.4 mm, 19 parts (0 on the bottom side), 14 nets.

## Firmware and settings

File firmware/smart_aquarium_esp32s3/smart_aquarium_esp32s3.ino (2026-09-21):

/*
 * ============================================================================
 *  SMART AQUARIUM IoT – ESP32-S3 DevKitC-1 (N8R8 / N16R8)
 *  Firmware v3.2.0 – RTC DS3231 + HiveMQ + backend Render ghi Postgres
 * ============================================================================
 *  v3.2 – ĐỔI MÀN HÌNH OLED -> LCD I2C (1602 hoặc 2004 + mạch PCF8574):
 *   - Driver LCD viết sẵn trong file này -> KHÔNG cần cài thư viện LCD nào.
 *   - Tự dò địa chỉ PCF8574 (0x27 / 0x3F và cả dải 0x20–0x27, 0x38–0x3F).
 *   - Chọn 16x2 hoặc 20x4 lúc chạy (lưu NVS): gõ "lcd 1602" / "lcd 2004" ở Serial
 *     hoặc bấm nút trên web, không cần nạp lại.
 *   - LCD 16x2: tự lật 2–3 trang mỗi 3 s. LCD 20x4: hiện đủ trên 1 trang.
 *   - Chỉ ghi lại dòng nào thay đổi -> không nhấp nháy, không làm chậm loop.
 *   - Cắm lại LCD khi đang chạy: tự nhận lại sau ≤ 5 s. Lệnh "lcd test": tô kín ô.
 *   - Giữ từ v3.1: quét bus I2C + đo điện dây SDA/SCL lúc khởi động, I2C 100 kHz,
 *     sửa lỗi gói gửi bù bị mất nhiệt độ.
 *
 *  Thư viện (Library Manager): PubSubClient, ArduinoJson (v7), OneWire,
 *  DallasTemperature, ESP32Servo, RTClib (Adafruit).
 *  -> KHÔNG cần U8g2 / Adafruit GFX / LiquidCrystal_I2C.
 * ============================================================================
 *  Thay đổi chính so với v1:
 *   - Thêm RTC DS3231 (I2C chung bus với LCD) + đồng bộ NTP -> lịch cho ăn
 *     vẫn chạy đúng giờ khi MẤT Wi-Fi / mất điện (pin CR2032 giữ giờ).
 *   - GIỮ NGUYÊN chân Relay/Còi như mạch cũ (GPIO19, GPIO18, GPIO12) vì đã chạy ổn.
 *   - Toàn bộ vòng lặp NON-BLOCKING: DS18B20 đọc bất đồng bộ, servo & còi
 *     chạy bằng state machine -> MQTT không bị rớt khi đang cho ăn.
 *   - Sửa lỗi manualOverrideChiller không bao giờ tự trả về AUTO.
 *   - Lớp an toàn: lỗi cảm biến -> tắt chiller + báo động; quá nóng -> ép bật;
 *     bơm tắt -> khóa chiller (không có dòng nước qua water block).
 *   - Quạt tản nhiệt tách riêng (MOSFET) + chạy trễ 60 s sau khi tắt sò.
 *   - Lưu cấu hình / lịch / bộ đếm vào NVS (Preferences) -> không mất khi reset.
 *   - MQTT: topic riêng theo nhóm, LWT online/offline, buffer 768 byte.
 *   - v2.1: lệnh web có phản hồi ACK (topic …/ack).
 *   - v2.2: ghi lịch sử lên API Vercel (/api/ingest → Postgres Neon) theo LÔ
 *     bằng task FreeRTOS riêng trên core 0 + hàng đợi (không làm chậm loop);
 *     hỗ trợ HiveMQ public (1883) hoặc HiveMQ Cloud (TLS 8883 + user/pass).
 *
 *  Board: esp32 by Espressif 2.0.x hoặc 3.x  ->  "ESP32S3 Dev Module"
 * ============================================================================
 */

#include <WiFi.h>
#include <PubSubClient.h>
#include <OneWire.h>
#include <DallasTemperature.h>
#include <ESP32Servo.h>
#include <Wire.h>
#include <ArduinoJson.h>
#include <RTClib.h>
#include <Preferences.h>
#include <time.h>
#include <sys/time.h>
#include <esp_sntp.h>
#include <WiFiClientSecure.h>
#include <HTTPClient.h>
#include <esp_system.h>

// ============================================================================
// 1. SƠ ĐỒ CHÂN – GIỮ NGUYÊN CHÂN MẠCH CŨ + thêm chân mới cho RTC/quạt/nút
//    Lưu ý: GPIO19 trùng USB D- → nạp code qua cổng "UART/COM", không dùng cổng "USB" (OTG).
//    Chân mới (7, 15, 16) không đụng chân cũ; không nối thì firmware vẫn chạy.
// ============================================================================
#define PIN_DS18B20        4    // 1-Wire. Có trở 4.7k lên 3V3 là tốt nhất
#define DS18B20_INTERNAL_PULLUP 1   // 1 = bật trở kéo NỘI của ESP32 (dùng khi KHÔNG gắn trở 4.7k, dây ngắn ≤ 1 m)
#define PIN_I2C_SDA        8    // LCD PCF8574 0x27/0x3F + DS3231 0x68 (+ EEPROM 0x57)
#define PIN_I2C_SCL        9
#define PIN_RTC_SQW        7    // (MỚI) DS3231 SQW – xung 1 Hz; không nối vẫn chạy
#define PIN_RELAY_CHILLER  19   // IN1: Relay 1 -> Sò Peltier + quạt (như cũ)
#define PIN_RELAY_PUMP     18   // IN2: Relay 2 -> Máy bơm 12V (như cũ)
#define PIN_FAN_MOSFET     15   // (tùy chọn, MỚI) quạt riêng qua IRLZ44N – quạt đang chung relay thì bỏ trống
#define PIN_SERVO_FEED     13   // MG90S PWM 50 Hz
#define PIN_BUZZER         12   // Còi active (như cũ)
#define PIN_BTN_TEST       0    // Nút BOOT: giữ 2 s -> Self-Test
#define PIN_BTN_FEED       16   // (MỚI, tùy chọn) nút cho ăn → GND

// Relay module Active-LOW như mạch cũ (LOW = đóng)
#define RELAY_ON   LOW
#define RELAY_OFF  HIGH

// ============================================================================
// 1b. LCD I2C (HD44780 + PCF8574) – 1602 hoặc 2004, chọn lúc chạy (NVS "lcdRows")
//     Đấu dây: GND->GND · VCC->5V (LCD cần 5V mới đủ tương phản) · SDA->GPIO8 · SCL->GPIO9
//     Có đèn nền mà KHÔNG thấy chữ -> vặn biến trở xanh sau lưng LCD (tương phản).
// ============================================================================
#define LCD_DEFAULT_ROWS 2          // 2 = LCD 1602 (16x2), 4 = LCD 2004 (20x4)
uint8_t lcdAddr   = 0;
uint8_t lcdRows   = LCD_DEFAULT_ROWS;
uint8_t lcdCols   = 16;
bool    lcdPresent   = false;
bool    lcdBacklight = true;
String  lcdShadow[4];               // nội dung đang hiện -> chỉ ghi dòng thay đổi
String  i2cList    = "";            // vd "27,57,68"
int     dsCount    = 0;             // số cảm biến DS18B20 tìm thấy
unsigned long lastLcdProbeMs = 0;

// ============================================================================
// 2. CẤU HÌNH
// ============================================================================
const char* FW_VERSION   = "3.2.0";
const char* WIFI_SSID    = "HO TRO SINH VIEN"; // Wi-Fi 2.4 GHz
const char* WIFI_PASS    = "12345678@";
// ---- MQTT: chọn 1 trong 2 ----
// (A) HiveMQ public:  MQTT_USE_TLS=false, host "broker.hivemq.com", port 1883, user/pass rỗng
// (B) HiveMQ Cloud :  MQTT_USE_TLS=true,  host "xxxxxxxx.s1.eu.hivemq.cloud", port 8883, user/pass của ESP32
const bool  MQTT_USE_TLS = false;
const char* MQTT_HOST    = "broker.hivemq.com";
const int   MQTT_PORT    = 1883;
const char* MQTT_USER    = "";                  // HiveMQ Cloud → Access Management → tài khoản "esp32"
const char* MQTT_PASS    = "";
// Đổi "nhomXX" thành mã nhóm – broker công cộng, topic trùng = người lạ điều khiển được bể!
const char* TOPIC_BASE   = "smartaquarium_node2026";   // PHẢI trùng TOPIC trong index.html

const char* TZ_INFO      = "ICT-7";            // Việt Nam UTC+7, không DST
const char* NTP_1        = "pool.ntp.org";
const char* NTP_2        = "time.google.com";

// ---- Ghi database: KHÔNG cần nữa vì backend trên Render tự nghe MQTT và ghi Postgres.
//      Chỉ bật khi muốn ESP32 tự POST HTTPS (kiến trúc cũ, không có backend).
const bool  DB_ENABLED        = false;
const char* API_BASE_URL      = "https://YOUR-APP.vercel.app";   // <--- domain PRODUCTION, không có "/" cuối
const char* DEVICE_KEY        = "";                              // để trống = không dùng khóa (API mở)
const unsigned long DB_TELEMETRY_PERIOD_MS = 60000;              // 1 bản ghi/phút
const int   DB_BATCH_MAX      = 20;                              // gộp tối đa 20 bản ghi / 1 request HTTPS

// Nhiệt độ (mặc định – có thể đổi từ Web, lưu NVS)
float SP_ON  = 27.0;   // >= bật chiller
float SP_OFF = 25.5;   // <= tắt chiller
const float TEMP_ALARM_HIGH = 30.0;   // ép bật chiller + còi
const float TEMP_ALARM_LOW  = 22.0;   // ép tắt chiller + còi
const float TEMP_VALID_MIN  = 0.0;
const float TEMP_VALID_MAX  = 50.0;

// Thời gian
const unsigned long SENSOR_PERIOD_MS     = 1000;
const unsigned long DS18B20_CONV_MS      = 400;       // 11-bit = 375 ms
const unsigned long TELEMETRY_PERIOD_MS  = 2000;
const unsigned long LCD_PERIOD_MS        = 500;
const unsigned long CHILLER_MIN_OFF_MS   = 60000UL;   // chống đóng/ngắt relay liên tục
const unsigned long FAN_POSTRUN_MS       = 60000UL;   // quạt chạy thêm sau khi tắt sò
const unsigned long MANUAL_TIMEOUT_MS    = 30UL * 60 * 1000; // MANUAL tự về AUTO
const unsigned long PUMP_RESUME_DELAY_MS = 5000;      // bơm chạy lại sau khi hộc đóng
const unsigned long WIFI_RETRY_MS        = 60000;   // Wi-Fi trường vào chậm → đừng ngắt quá sớm
const unsigned long MQTT_RETRY_MS        = 5000;
const unsigned long RTC_WRITE_PERIOD_MS  = 6UL * 3600 * 1000;  // ghi giờ NTP -> RTC
const unsigned long RTC_RESEED_PERIOD_MS = 10UL * 60 * 1000;   // offline: RTC -> hệ thống

// Cho ăn
const int  MAX_SLOTS          = 4;
const int  FEED_GRACE_MIN     = 30;   // khởi động lại trễ <= 30 phút vẫn cho ăn bù
const int  MIN_FEED_GAP_MIN   = 30;   // 2 lần cho ăn cách nhau tối thiểu 30 phút
const int  MAX_FEEDS_PER_DAY  = 6;    // chống cho ăn quá tay
const int  SERVO_OPEN_DEG     = 110;
const unsigned long SERVO_HOLD_MS = 1000;

// ============================================================================
// 3. ĐỐI TƯỢNG & TRẠNG THÁI
// ============================================================================
WiFiClient        mqttPlain;
WiFiClientSecure  mqttSecure;
PubSubClient      mqtt;                        // client gắn trong setup() theo MQTT_USE_TLS
OneWire           oneWire(PIN_DS18B20);
DallasTemperature ds18b20(&oneWire);
Servo             feedServo;
RTC_DS3231        rtc;
Preferences       prefs;

String topicTelemetry, topicCommand, topicStatus, topicEvent, topicAck, deviceId;

// Nhiệt độ
float currentTemp  = NAN;
bool  sensorFault  = true;
int   sensorErrCnt = 0;
bool  convPending  = false;
unsigned long convStartMs = 0, lastSensorMs = 0;

// Cơ cấu chấp hành
bool chillerOn = false, pumpWanted = true, pumpOn = true, fanOn = false;
unsigned long chillerOffAtMs = 0;
bool autoMode = true;
bool manualChillerReq = false;   // trạng thái người dùng yêu cầu ở chế độ MANUAL
unsigned long manualSinceMs = 0;

// Báo động
enum AlarmCode { ALM_NONE, ALM_SENSOR, ALM_HIGH, ALM_LOW, ALM_TIME };
AlarmCode alarmCode = ALM_NONE, lastAlarm = ALM_NONE;
bool alarmMuted = false;
unsigned long lastAlarmBeepMs = 0;

// Đo đạc / an toàn khi mất mạng
uint32_t telemetrySeq = 0;              // số thứ tự gói → web tính tỉ lệ mất gói
bool safeMode = false;                  // mất broker > 30 s: tự quản lý cục bộ
unsigned long mqttLostAtMs = 0;
uint32_t bufferedSent = 0;

// Bộ đệm khi mất mạng: 1 bản ghi/phút, giữ 240 phút gần nhất
struct BufRec { uint32_t t; float temp; uint8_t flags; uint8_t feedToday; };
const int  BUF_MAX = 240;
BufRec  buf[BUF_MAX];
int     bufHead = 0, bufCount = 0;
unsigned long lastBufMs = 0;

// Thời gian
bool rtcPresent = false;
bool dbActive = false;          // DB chỉ chạy khi DB_ENABLED và API_BASE_URL đã sửa
bool timeValid  = false;
enum TimeSrc { SRC_NONE, SRC_RTC, SRC_NTP, SRC_WEB };
TimeSrc timeSrc = SRC_NONE;
volatile bool rtcTickFlag  = false;
volatile bool ntpSyncFlag  = false;
unsigned long lastTickMs = 0, lastRtcWriteMs = 0, lastReseedMs = 0;
bool everNtp = false;

// Lịch cho ăn
struct FeedSlot { uint8_t h; uint8_t m; };
FeedSlot slots[MAX_SLOTS];
int      slotCount = 0;
uint32_t lastSchedFed = 0;   // epoch của slot gần nhất đã xử lý
uint32_t lastFeedEpoch = 0;
uint32_t feedDayKey = 0;
uint16_t feedToday = 0;
uint32_t feedTotal = 0;

// State machine cho ăn
enum FeedState { FEED_IDLE, FEED_OPEN, FEED_HOLD, FEED_CLOSE, FEED_RESUME };
FeedState feedState = FEED_IDLE;
int  servoPos = 0;
unsigned long feedStepMs = 0;
String feedSource = "";

// Còi non-blocking
int  buzzRemain = 0; unsigned long buzzOnMs = 0, buzzOffMs = 0, buzzNextMs = 0; bool buzzState = false;

// Kết nối / chu kỳ
unsigned long lastWifiTryMs = 0, lastMqttTryMs = 0, lastTelemetryMs = 0, lastLcdMs = 0;
bool selfTestRequested = false;

// Nút nhấn
bool btnFeedPrev = HIGH, btnTestPrev = HIGH;
unsigned long btnFeedChangeMs = 0, btnTestDownMs = 0;

// ============================================================================
// 4. TIỆN ÍCH
// ============================================================================
void IRAM_ATTR onRtcSqw() { rtcTickFlag = true; }
void onNtpSync(struct timeval *tv) { ntpSyncFlag = true; }

void beep(int count, unsigned long onMs = 80, unsigned long offMs = 80) {
  buzzRemain = count; buzzOnMs = onMs; buzzOffMs = offMs;
  buzzNextMs = millis(); buzzState = false;
}

void updateBuzzer(unsigned long now) {
  if (buzzRemain <= 0 || now < buzzNextMs) return;
  if (!buzzState) { digitalWrite(PIN_BUZZER, HIGH); buzzState = true;  buzzNextMs = now + buzzOnMs; }
  else            { digitalWrite(PIN_BUZZER, LOW);  buzzState = false; buzzNextMs = now + buzzOffMs; buzzRemain--; }
}

bool getLocal(struct tm &t) {
  if (!timeValid) return false;
  time_t e = time(nullptr);
  localtime_r(&e, &t);
  return true;
}

String fmtTime(bool withDate) {
  struct tm t;
  if (!getLocal(t)) return withDate ? "----------" : "--:--:--";
  char b[24];
  if (withDate) strftime(b, sizeof(b), "%Y-%m-%d %H:%M:%S", &t);
  else          strftime(b, sizeof(b), "%H:%M:%S", &t);
  return String(b);
}

const char* srcName(TimeSrc s) {
  switch (s) { case SRC_RTC: return "RTC"; case SRC_NTP: return "NTP"; case SRC_WEB: return "WEB"; default: return "NONE"; }
}
const char* alarmName(AlarmCode a) {
  switch (a) { case ALM_SENSOR: return "SENSOR_FAULT"; case ALM_HIGH: return "TEMP_HIGH";
               case ALM_LOW: return "TEMP_LOW"; case ALM_TIME: return "TIME_INVALID"; default: return "NONE"; }
}

// ============================================================================
// 4b. GHI DATABASE – TASK FreeRTOS RIÊNG (core 0) + HÀNG ĐỢI + GỬI THEO LÔ
//     loop() chỉ đẩy JSON vào queue (không chờ). dbTask gom tối đa
//     DB_BATCH_MAX bản ghi rồi POST 1 lần lên API_BASE_URL/api/ingest.
//     Mất Wi-Fi: dữ liệu nằm chờ trong queue (40 bản ghi).
// ============================================================================
struct DbJob { char table[12]; char* json; };
QueueHandle_t dbQueue = nullptr;
volatile uint32_t dbOk = 0, dbFail = 0, dbDropped = 0;
unsigned long lastDbTelemetryMs = 0;

void dbEnqueue(const char* table, JsonDocument &row) {
  if (!dbActive || dbQueue == nullptr || deviceId.length() < 3) return;
  row["device_id"] = deviceId;
  if (timeValid) {                                   // gắn giờ thực của thiết bị (UTC)
    time_t e = time(nullptr); struct tm u; gmtime_r(&e, &u);
    char iso[24]; strftime(iso, sizeof(iso), "%Y-%m-%dT%H:%M:%SZ", &u);
    row["created_at"] = iso;
  }
  String out; serializeJson(row, out);
  DbJob job; strncpy(job.table, table, sizeof(job.table) - 1); job.table[sizeof(job.table) - 1] = 0;
  job.json = strdup(out.c_str());
  if (job.json == nullptr) { dbDropped++; return; }
  if (xQueueSend(dbQueue, &job, 0) != pdTRUE) { free(job.json); dbDropped++; }
}

void dbTask(void*) {
  WiFiClientSecure tls;
  tls.setInsecure();              // bài học: bỏ kiểm tra chứng chỉ. Sản phẩm thật: tls.setCACert(rootCA)
  HTTPClient http;
  http.setReuse(true);            // giữ kết nối HTTPS giữa các lô → đỡ tốn thời gian bắt tay TLS
  DbJob batch[DB_BATCH_MAX];
  const String url = String(API_BASE_URL) + "/api/ingest";

  for (;;) {
    int n = 0;
    if (xQueueReceive(dbQueue, &batch[n], portMAX_DELAY) != pdTRUE) continue;
    n++;
    // gom thêm bản ghi đến trong 2 s (sự kiện thường đi thành chùm)
    while (n < DB_BATCH_MAX && xQueueReceive(dbQueue, &batch[n], pdMS_TO_TICKS(2000)) == pdTRUE) n++;

    String body; body.reserve(n * 260 + 16);
    body = "{\"items\":[";
    for (int i = 0; i < n; i++) {
      if (i > 0) body += ",";
      body += "{\"t\":\""; body += batch[i].table; body += "\",\"r\":"; body += batch[i].json; body += "}";
    }
    body += "]}";

    while (WiFi.status() != WL_CONNECTED) vTaskDelay(pdMS_TO_TICKS(2000));
    bool done = false;
    for (int attempt = 0; attempt < 3 && !done; attempt++) {
      if (!http.begin(tls, url)) { vTaskDelay(pdMS_TO_TICKS(2000)); continue; }
      http.setTimeout(10000);
      http.addHeader("Content-Type", "application/json");
      if (strlen(DEVICE_KEY)) http.addHeader("x-device-key", DEVICE_KEY);
      int code = http.POST(body);
      if (code == 200) { done = true; dbOk += n; }
      else {
        Serial.printf("[DB] HTTP %d %s\n", code, code > 0 ? http.getString().c_str() : "(mat ket noi)");
        if (code >= 400 && code < 500) { http.end(); break; }   // sai khóa / dữ liệu: không thử lại
        vTaskDelay(pdMS_TO_TICKS(3000 * (attempt + 1)));
      }
      http.end();
    }
    if (!done) dbFail += n;
    for (int i = 0; i < n; i++) free(batch[i].json);
  }
}

void dbLogTelemetry() {
  JsonDocument r;
  if (sensorFault) r["temp"] = nullptr; else r["temp"] = round(currentTemp * 10) / 10.0;
  r["chiller"] = chillerOn; r["pump"] = pumpOn; r["fan"] = fanOn;
  r["mode"] = autoMode ? "AUTO" : "MANUAL";
  r["feed_today"] = feedToday; r["feed_total"] = feedTotal;
  r["alarm"] = alarmName(alarmCode);
  if (rtcPresent) r["rtc_temp"] = round(rtc.getTemperature() * 10) / 10.0;
  r["rssi"] = WiFi.RSSI();
  r["time_src"] = srcName(timeSrc);
  dbEnqueue("telemetry", r);
}

void publishEvent(const String &type, const String &detail) {
  Serial.printf("[EVENT] %s: %s\n", type.c_str(), detail.c_str());
  { JsonDocument r; r["type"] = type.substring(0, 24); r["detail"] = detail.substring(0, 200); dbEnqueue("events", r); }
  if (!mqtt.connected()) return;
  JsonDocument d;
  d["type"] = type; d["detail"] = detail; d["time"] = fmtTime(true);
  String out; serializeJson(d, out);
  mqtt.publish(topicEvent.c_str(), out.c_str());
}

// ============================================================================
// 5. THỜI GIAN THỰC: RTC DS3231 <-> ĐỒNG HỒ HỆ THỐNG <-> NTP
// ============================================================================
void setSystemTime(time_t e) { struct timeval tv = { e, 0 }; settimeofday(&tv, nullptr); }

bool seedSystemFromRtc() {
  if (!rtcPresent) return false;
  DateTime d = rtc.now();
  if (d.year() < 2024 || d.year() > 2099) return false;
  struct tm t = {};
  t.tm_year = d.year() - 1900; t.tm_mon = d.month() - 1; t.tm_mday = d.day();
  t.tm_hour = d.hour(); t.tm_min = d.minute(); t.tm_sec = d.second(); t.tm_isdst = -1;
  setSystemTime(mktime(&t));      // RTC lưu GIỜ ĐỊA PHƯƠNG (UTC+7)
  return true;
}

void writeRtcFromSystem() {
  if (!rtcPresent) return;
  time_t e = time(nullptr);
  struct tm t; localtime_r(&e, &t);
  rtc.adjust(DateTime(t.tm_year + 1900, t.tm_mon + 1, t.tm_mday, t.tm_hour, t.tm_min, t.tm_sec));
  lastRtcWriteMs = millis();
}

void initTime() {
  setenv("TZ", TZ_INFO, 1); tzset();
  rtcPresent = rtc.begin(&Wire);
  if (!rtcPresent) { Serial.println("[RTC] Khong tim thay DS3231 (0x68)!"); return; }

  rtc.disable32K();
  rtc.writeSqwPinMode(DS3231_SquareWave1Hz);
  pinMode(PIN_RTC_SQW, INPUT_PULLUP);
  attachInterrupt(digitalPinToInterrupt(PIN_RTC_SQW), onRtcSqw, FALLING);

  if (rtc.lostPower()) {
    Serial.println("[RTC] Mat nguon pin -> gio khong hop le, cho NTP/Web");
  } else if (seedSystemFromRtc()) {
    timeValid = true; timeSrc = SRC_RTC; lastReseedMs = millis();
    Serial.printf("[RTC] Gio tu DS3231: %s\n", fmtTime(true).c_str());
  }
}

void handleTimeSync(unsigned long now) {
  if (ntpSyncFlag) {                          // cờ đặt từ task SNTP -> xử lý I2C ở loop
    ntpSyncFlag = false;
    bool first = !everNtp;
    everNtp = true; timeValid = true; timeSrc = SRC_NTP;
    if (first || now - lastRtcWriteMs >= RTC_WRITE_PERIOD_MS) {
      writeRtcFromSystem();
      publishEvent("time_sync", String("NTP -> RTC ") + fmtTime(true));
    }
    lastReseedMs = now;
  }
  // Offline lâu: đồng hồ thạch anh ESP32 trôi -> lấy lại giờ từ TCXO DS3231 (±2 ppm)
  if (rtcPresent && timeValid && WiFi.status() != WL_CONNECTED &&
      now - lastReseedMs >= RTC_RESEED_PERIOD_MS) {
    if (seedSystemFromRtc()) timeSrc = SRC_RTC;
    lastReseedMs = now;
  }
}

// ============================================================================
// 6. NVS
// ============================================================================
String scheduleToString() {
  String s;
  for (int i = 0; i < slotCount; i++) {
    char b[6]; snprintf(b, sizeof(b), "%02d:%02d", slots[i].h, slots[i].m);
    if (i > 0) s += ",";
    s += b;
  }
  return s;
}
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
void loop() {
  unsigned long now = millis();

  handleConnectivity(now);
  handleTimeSync(now);
  updateSensor(now);
  updateFeeding(now);
  updateBuzzer(now);
  handleButtons(now);

  // Nhịp 1 giây: ưu tiên xung SQW của DS3231, dự phòng bằng millis()
  bool secondTick = false;
  if (rtcTickFlag) { rtcTickFlag = false; secondTick = true; lastTickMs = now; }
  else if (now - lastTickMs >= 1500) { secondTick = true; lastTickMs = now; }
  if (secondTick) {
    checkSchedule();
    applyOutputs(now);          // cập nhật quạt chạy trễ
    handleAlarm(now);
  }

  handleLcdHotplug(now);
  if (lcdPresent && now - lastLcdMs >= LCD_PERIOD_MS) { lastLcdMs = now; renderLCD(now); }

  if (now - lastTelemetryMs >= TELEMETRY_PERIOD_MS) {
    lastTelemetryMs = now;
    if (mqtt.connected()) sendTelemetry();
    else bufferPush(now);                 // mất mạng: cất vào bộ đệm
  }

  static unsigned long lastFlushMs = 0;   // có mạng lại: gửi bù 5 bản ghi/200 ms
  if (bufCount > 0 && mqtt.connected() && now - lastFlushMs >= 200) { lastFlushMs = now; bufferFlush(); }

  if (now - lastDbTelemetryMs >= DB_TELEMETRY_PERIOD_MS) {
    lastDbTelemetryMs = now;
    dbLogTelemetry();
  }

  if (selfTestRequested) { selfTestRequested = false; runSelfTest(); }
  handleSerialCommand(now);

  static unsigned long lastBeat = 0;               // nhịp tim Serial: nhìn là biết đang kẹt ở đâu
  if (now - lastBeat >= 10000) {
    lastBeat = now;
    Serial.printf("[SYS] uptime %lus | WiFi %s | MQTT %s (state=%d) | T=%s | LCD %s | heap %u\n",
                  now / 1000, WiFi.status() == WL_CONNECTED ? "OK" : "CHUA",
                  mqtt.connected() ? "OK" : "CHUA", mqtt.state(),
                  sensorFault ? "ERR" : String(currentTemp, 1).c_str(), lcdStatus().c_str(), (unsigned)ESP.getFreeHeap());
  }
}

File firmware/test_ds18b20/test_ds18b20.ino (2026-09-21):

/*
 * TEST CẢM BIẾN DS18B20 – ESP32-S3 (chẩn đoán "Mất cảm biến" / ERR / -127°C)
 * ---------------------------------------------------------------------------
 * Thư viện: OneWire, DallasTemperature (đã cài cho firmware chính).
 * Nạp, mở Serial Monitor 115200.
 *
 * Nối dây DS18B20 (loại dây chống nước 3 sợi):
 *   ĐỎ   (VCC)  -> 3V3
 *   ĐEN  (GND)  -> GND
 *   VÀNG (DATA) -> GPIO4
 *   Trở 4.7kΩ nối giữa VÀNG và ĐỎ (DATA lên 3V3)  <-- RẤT NÊN CÓ
 *
 * Chương trình kiểm tra:
 *   B1. Dây DATA có trở kéo lên ngoài không (4.7k)?
 *   B2. Có cảm biến trả lời trên GPIO4 không (xung "presence") – thử cả có/không trở kéo nội
 *   B3. Dò các chân khác: cảm biến có bị cắm nhầm chân không?
 *   B4. Đọc 20 lần, đếm số lần lỗi -> biết dây chập chờn hay ổn định
 */
#include <OneWire.h>
#include <DallasTemperature.h>

const int DS_PIN = 4;
// Chân an toàn để dò (không đụng relay 18/19, I2C 8/9, còi 12, servo 13, quạt 15, UART 43/44)
const int CAND[] = { 1, 2, 4, 5, 6, 7, 10, 11, 14, 16, 17, 21, 38, 39, 40, 41, 42, 47, 48 };

bool hasExternalPullup(int pin) {
  pinMode(pin, INPUT_PULLDOWN);
  delay(5);
  int hi = 0;
  for (int i = 0; i < 10; i++) { hi += digitalRead(pin); delayMicroseconds(200); }
  pinMode(pin, INPUT);
  return hi >= 9;
}

bool presenceOn(int pin, bool internalPullup) {
  OneWire ow(pin);
  if (internalPullup) pinMode(pin, INPUT_PULLUP);
  delay(2);
  bool ok = false;
  for (int i = 0; i < 3 && !ok; i++) ok = ow.reset();
  return ok;
}

void setup() {
  Serial.begin(115200);
  delay(2000);
  Serial.println("\n================ TEST DS18B20 ================");

  // ---------- B1 ----------
  bool ext = hasExternalPullup(DS_PIN);
  Serial.printf("\n[B1] Tro keo len ngoai tren GPIO%d: %s\n", DS_PIN,
                ext ? "CO (da gan 4.7k hoac tuong duong) -> tot" : "KHONG CO -> dang dua vao tro keo NOI ~45k (yeu, de mat cam bien)");

  // ---------- B2 ----------
  bool pNo  = presenceOn(DS_PIN, false);
  bool pInt = presenceOn(DS_PIN, true);
  Serial.printf("[B2] Cam bien tra loi tren GPIO%d: khong keo noi = %s | co keo noi = %s\n",
                DS_PIN, pNo ? "CO" : "KHONG", pInt ? "CO" : "KHONG");

  // ---------- B3 ----------
  int foundOther = -1;
  if (!pNo && !pInt) {
    Serial.println("[B3] Do cac chan khac (co keo noi)...");
    for (int p : CAND) {
      if (p == DS_PIN) continue;
      if (presenceOn(p, true)) { Serial.printf("   ✔ Thay DS18B20 o GPIO%d !\n", p); foundOther = p; }
    }
    if (foundOther < 0) Serial.println("   Khong thay DS18B20 o chan nao.");
  }

  // ---------- B4 ----------
  int errs = 0, ok = 0, n = 0;
  if (pNo || pInt) {
    pinMode(DS_PIN, INPUT_PULLUP);
    OneWire ow(DS_PIN);
    DallasTemperature ds(&ow);
    ds.begin();
    pinMode(DS_PIN, INPUT_PULLUP);                    // bật lại kéo nội sau begin()
    n = ds.getDeviceCount();
    DeviceAddress a;
    Serial.printf("[B4] So cam bien: %d", n);
    if (n && ds.getAddress(a, 0)) {
      Serial.print(" | dia chi ROM: ");
      for (int i = 0; i < 8; i++) Serial.printf("%02X", a[i]);
      Serial.printf(" | che do: %s", ds.isParasitePowerMode() ? "KY SINH (day DO chua noi 3V3!)" : "cap nguon rieng (dung)");
    }
    Serial.println();
    ds.setResolution(11);
    for (int i = 0; i < 20; i++) {
      ds.requestTemperatures();
      float t = ds.getTempCByIndex(0);
      bool bad = (t == DEVICE_DISCONNECTED_C) || (t == 85.0f);
      if (bad) errs++; else ok++;
      Serial.printf("   lan %2d: %s\n", i + 1, bad ? (t == 85.0f ? "85.0 (loi: nguon yeu / doc qua som)" : "-127 (mat tin hieu)") : String(t, 2).c_str());
      delay(300);
    }
  }

  // ---------- KẾT LUẬN ----------
  Serial.println("\n================ KET LUAN ================");
  if ((pNo || pInt) && errs == 0) {
    Serial.printf("✔ DS18B20 hoat dong tot (%d/20 lan doc OK).", ok);
    Serial.println(ext ? "" : " Van NEN gan tro 4.7k de chay lau dai khong mat.");
    Serial.println("  Neu firmware chinh van bao ERR -> nap lai firmware v3.2.0 moi nhat.");
  } else if ((pNo || pInt) && errs > 0) {
    Serial.printf("⚠ Cam bien CHAP CHON: %d/20 lan loi.\n", errs);
    Serial.println("  -> Nguyen nhan so 1: THIEU TRO 4.7k. Gan tro 4.7k giua day VANG (DATA) va DO (3V3).");
    Serial.println("  -> Khong co 4.7k: dung tam 2 tro 10k mac song song (=5k), hoac 1 tro 2.2k–10k bat ky.");
    Serial.println("  -> Kiem tra moi han / day cam breadboard long.");
  } else if (foundOther >= 0) {
    Serial.printf("✘ Ban cam day VANG (DATA) vao GPIO%d, khong phai GPIO4. Cam lai vao GPIO4.\n", foundOther);
  } else {
    Serial.println("✘ Khong co cam bien nao tra loi:");
    Serial.println("  1. Do: VCC(3V3) - GND - DATA dung mau? (DO=3V3, DEN=GND, VANG=DATA)");
    Serial.println("     Mot so cam bien mau khac: DO=VCC, VANG/TRANG=DATA, DEN/XANH=GND.");
    Serial.println("  2. Cam nguoc VCC/GND lau co the lam CHAY cam bien (cam bien nong khi cham tay).");
    Serial.println("  3. Gan tro 4.7k DATA-3V3 roi thu lai – keo noi thuong KHONG du voi day dai 1 m.");
  }
  Serial.println("\n(Nhan RESET de do lai)");
}

void loop() {}

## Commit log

2026-09-08 Chuyen File Excel vao thu muc Docs
    [danh_sach_mua_sam_ho_ca_smart.xlsx, tien_do_du_an_ho_ca_smart.xlsx]
2026-09-17 update 6
    [danh_sach_mua_sam_v1.1.xlsx]
2026-09-21 Create Character-device
